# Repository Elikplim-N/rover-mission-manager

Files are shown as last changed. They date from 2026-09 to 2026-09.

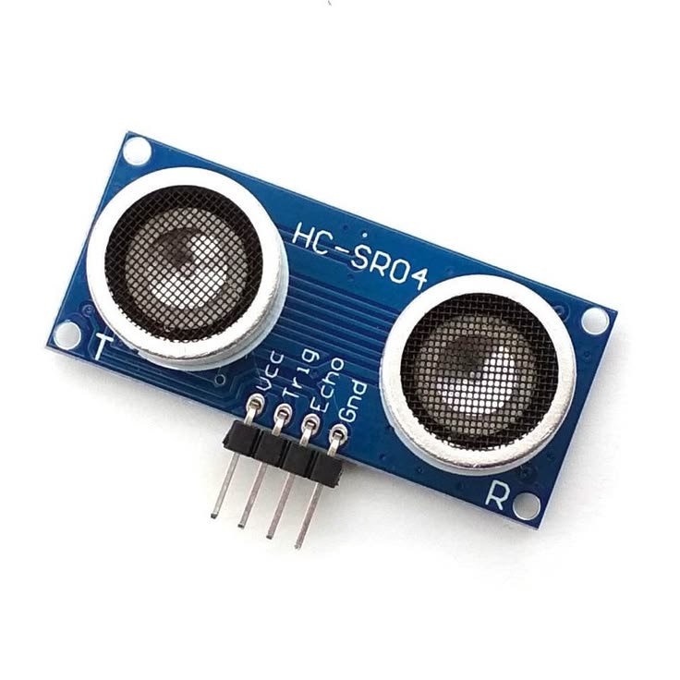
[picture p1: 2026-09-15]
docs/thesis/photos/hc_sr04_ultrasonic.jpg

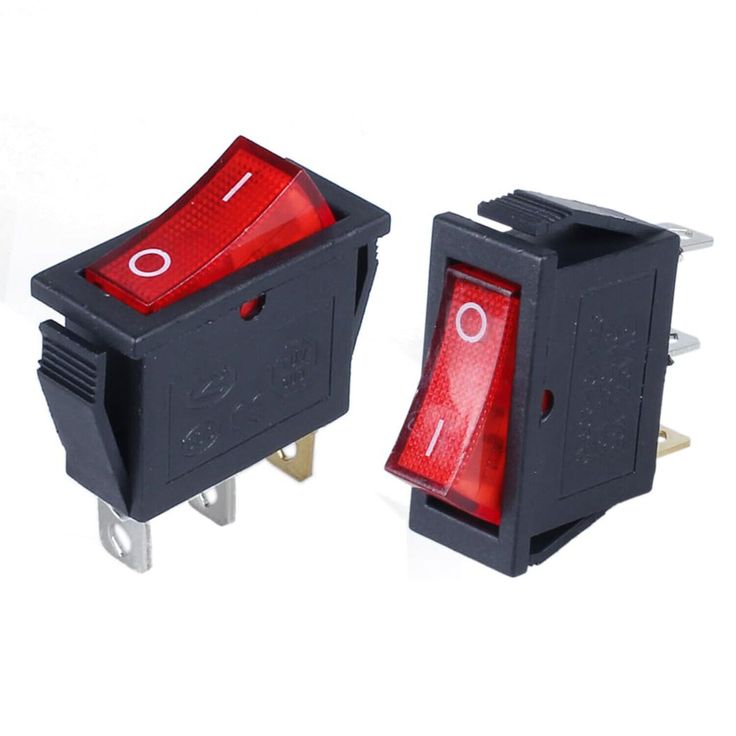
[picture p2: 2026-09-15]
docs/thesis/photos/power_rocker_switch.jpg

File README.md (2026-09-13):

# Autonomous Maize Rover: Mission Manager & Cloud IoT Ecosystem








An integrated precision agriculture cyber-physical system for autonomous maize planting, micro-irrigation, multi-sensor terrain telemetry, real-time cloud ingestion, remote E-Stop safety, and 3D digital-twin visualization.

---

## Architecture Topology

```
Sensors → Arduino Uno R4 WiFi → Wi-Fi HTTP POST → Dokploy (Node/Express + PostgreSQL 18.6) → Web Workstation
```

```mermaid
flowchart LR
    subgraph Rover["Edge: Arduino Uno R4 WiFi"]
        Sensors["BME280, MPU6050, Compass, GPS, Moisture, Ultrasonic"]
        Actuators["Motors, Seed Servo, Arm Servo, Pump Relay, Buzzer, NeoPixels"]
        MCU["Renesas RA4M1 + ESP32-S3"]
        Sensors --> MCU --> Actuators
    end

    subgraph Dokploy["Cloud: Dokploy PaaS (178.105.184.157:6000)"]
        API["rover-api (Port 3001)"]
        DB[("PostgreSQL 18.6\n(rover-hub)")]
        API --> DB
    end

    subgraph Workstation["Workstation: Rover Mission Manager"]
        ThreeD["Three.js 3D Digital Twin"]
        Analytics["Plotly.js Agronomic Analytics"]
        Teleop["Manual Control & E-Stop Room"]
        Dexie[("IndexedDB Local Cache")]
    end

    MCU -->|HTTP POST /api/telemetry| API
    MCU <-->|Direct Subnet Port 8080| Teleop
    API <-->|REST Sync & Command Relay| Workstation
    Workstation --> Dexie
```

---

## Key Features

1. **Pure Cloud-First IoT Pipeline (No SD Card)**:
   - Physical SD card breakouts are eliminated by design, avoiding SPI pin collisions with seed servos, buzzers, arm servos, and NeoPixel status lights.
   - Dedicates Pin `D4` strictly to **Left Motor Enable (`MOTOR_LEFT_EN`)**.
   - Completely removes mechanical socket vibration failures over furrow soil.
2. **Preemptive 3-State Machine & Remote E-Stop**:
   - `AUTO_MISSION`: Autonomous boustrophedon furrow traversal and periodic planting cycle.
   - `MANUAL_OVERRIDE`: Allows operator to drive the rover (WASD / arrow keys) and test individual actuators for defense demo.
   - `EMERGENCY_STOP`: Immediate remote safety kill (0% PWM, forced pump cut, warning buzzer horn, flashing red LEDs).
   - Embedded `WiFiServer` on **Port 8080** for direct `<20ms` latency control on the field Wi-Fi / mobile hotspot.
3. **Relative Micro-Topography Tare Engine**:
   - Automatically averages 12 barometric altitude samples during boot with the Bosch BME280.
   - Computes relative elevation $\Delta \text{Elev} = \text{Alt}_{\text{current}} - \text{Alt}_{\text{baseline}}$ for real-time 3D terrain reconstruction.
4. **Production Dokploy Ingestion Stack**:
   - Containerized Express REST service on port `3001`.
   - Connected live to **PostgreSQL 18.6** (`rover-hub` on `178.105.184.157:6000`).
5. **Interactive 3D Digital Twin**:
   - Three.js WebGL surface reconstruction with dynamic elevation heatmaps and boustrophedon furrow playback.
   - Smooth spherical linear interpolation (`slerp`) matching MPU-6050 pitch and roll.

---

## Repository Structure

```
├── docs/
│   └── ARCHITECTURE_KNOWLEDGE_BASE.md   # Complete system architecture specification
├── firmware/
│   ├── MaizeRover_Phase2_Master/        # Arduino Uno R4 WiFi firmware (.ino)
│   │   └── MaizeRover_Phase2_Master.ino
│   └── README.md                        # Pinout manual & hardware guide
├── server/                              # Dokploy Cloud Ingestion API
│   ├── Dockerfile                       # Production Node 20 container
│   ├── docker-compose.yml               # 1-click Dokploy stack definition
│   ├── db.js                            # PostgreSQL auto-migration & client
│   ├── index.js                         # REST endpoints (/api/telemetry, /api/command, /api/missions)
│   └── package.json
└── src/                                 # Web Application Workstation
    ├── components/
    │   ├── Layout.tsx                   # Navbar with global quick E-Stop trigger
    │   └── Terrain3D.tsx                # Three.js 3D terrain & rover kinematic visualizer
    ├── pages/
    │   ├── Dashboard.tsx                # Fleet operations & quick cloud sync
    │   ├── Teleop.tsx                   # Manual control pad, E-Stop, and actuator test bench
    │   ├── Library.tsx                  # Mission Hub & Dokploy synchronization
    │   ├── MissionView.tsx              # Detailed 3D playback & telemetry inspector
    │   ├── Analytics.tsx                # Multi-series Plotly agronomic charts
    │   ├── Fields.tsx                   # Agricultural plot boundary manager
    │   └── Planner.tsx                  # Furrow path planning & simulation
    └── lib/
        ├── api.ts                       # Dokploy REST client & direct LAN teleop driver
        ├── db.ts                        # Dexie.js IndexedDB schema
        └── utils.ts                     # Telemetry parsers & mathematical models
```

---

## 19-Channel Telemetry Schema

```csv
Row,Drop,SynX,SynY,Volt,TempC,Hum,Press,Elev,Moist,Watered,AbsHead,Err,Pitch,Roll,Lat,Lng,Sats,ObsDist
```

| Field | Type | Description |
| :--- | :--- | :--- |
| `Row`, `Drop` | Int | Furrow row index and planted drop index |
| `SynX`, `SynY`| Float (m) | Local orthogonal Cartesian grid coordinates |
| `Volt` | Float (V) | Rover battery voltage bus |
| `TempC`, `Hum`, `Press` | Float | Ambient canopy temperature (°C), humidity (%), and pressure (hPa) |
| `Elev` | Float (m) | Relative terrain micro-elevation above baseline |
| `Moist`, `Watered` | Int / Bool | Soil moisture reading (0–1023) and irrigation dose flag |
| `AbsHead`, `Err` | Float (deg) | Compass azimuth and furrow course tracking error |
| `Pitch`, `Roll` | Float (deg) | Fore-aft and transverse rover inclination angles |
| `Lat`, `Lng`, `Sats` | Float / Int | GNSS coordinates and satellite count |
| `ObsDist` | Float (cm) | Distance to nearest forward obstacle |

---

## Getting Started

### 1. Web Workstation (Frontend)
```bash
# Install dependencies
npm install

# Run locally in development mode
npm run dev
# Accessible at http://localhost:5173

# Build production bundle
npm run build
```

### 2. Dokploy Backend Deployment
```bash
cd server
npm install
npm start
# Runs on http://localhost:3001
```
Or deploy [`server/docker-compose.yml`](server/docker-compose.yml) directly in Dokploy.

### 3. Flashing the Rover
1. Open [`firmware/MaizeRover_Phase2_Master/MaizeRover_Phase2_Master.ino`](firmware/MaizeRover_Phase2_Master/MaizeRover_Phase2_Master.ino) in the Arduino IDE.
2. Select **Board: Arduino Uno R4 WiFi**.
3. Update `WIFI_SSID` and `WIFI_PASS` with your farm Wi-Fi or mobile hotspot credentials.
4. Upload to the rover.

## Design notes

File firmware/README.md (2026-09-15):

# Maize Rover: Phase 2 Master Firmware (Arduino Uno R4 WiFi)

## Architectural Model: Local-First, No Internet Required in the Field

This firmware hosts its own WiFi network (Access Point mode) instead of joining a farm router or phone hotspot. A phone or laptop connects directly to the rover's network and controls it over the local subnet — mission configuration, start/pause/resume, manual teleop, and telemetry are all served from the rover itself at a fixed address, with no dependency on mobile data or an internet connection reaching the field. A completed mission is logged on the connecting device and can be pushed to the cloud afterward, from the app, purely for later analysis.

There is also no SD card. Rather than relying on fragile physical MicroSD cards and SPI bus wiring, the Arduino Uno R4 WiFi's pins that would otherwise be reserved for an SD breakout are freed up for actuators and status indicators.

---

## Architectural Advantages of the No-SD-Card Design

1. **Elimination of Pin Contention**:
   - Standard SPI SD breakouts require pins D10 (CS), D11 (MOSI), D12 (MISO), and D13 (SCK).
   - In our rover, pins D10–D13 are dedicated to:
     - `D10`: Seed Dispenser Servo
     - `D11`: Active Buzzer
     - `D12`: Articulated Arm Servo
     - `D13`: WS2812B NeoPixel RGB
   - Eliminating the SD card frees pin `D4` completely for **Left Motor Enable (`MOTOR_LEFT_EN`)**, preventing pin conflicts and erratic motor behavior.
2. **Reduced Mechanical & Electrical Failure Points**:
   - SD card sockets frequently disconnect or corrupt files under high rover vibration over rough furrow soil.
   - Saves ~80mA current spikes from the 5V regulator.
3. **Local-First Mission Data**:
   - Every drop's telemetry is held on the rover in a live snapshot (`/cmd?action=status`) and logged by the connecting app straight to that device's own storage, with no server or connection required for the mission to run or be recorded.
   - A mission can be pushed to the cloud afterward, from the app, whenever it happens to have an internet connection — this is for later analysis only and is never on the rover's critical path.

---

## Telemetry Pipelines

1. **Pipeline 1 (Local Command/Status Server, Port 8080)**:
   - Serves mission lifecycle commands (`config`, `start_mission`, `pause_mission`, `resume_mission`, `status`) and manual teleop/E-Stop over the rover's own WiFi network.
   - `status` returns the latest telemetry snapshot and mission progress; a companion app polls this to log each drop on-device.
2. **Pipeline 2 (Local USB / Telemetry Radio)**:
   - Prints the standard 19-column CSV row at 115200 baud on USB Serial for local laptop debugging and radio receivers.

---

## Pinout Map

| Arduino Uno R4 Pin | Subsystem | Function |
| :--- | :--- | :--- |
| **A4 (SDA) / A5 (SCL)**| I2C Bus | BME280 (`0x76`), MPU-6050 (`0x68`), Compass (`0x1E`) |
| **A0** | Analog | Soil Moisture Probe |
| **A1** | Analog | Rover Battery Voltage Divider (B25 module, 5:1, 0-25V) |
| **A2 / A3** | GPIO / Timer | Ultrasonic HC-SR04 Trigger & Echo |
| **D3 / D5** | PWM | Left Motor RPWM / LPWM |
| **D4** | Digital Output | Left Motor Enable (`HIGH`) |
| **D6 / D9** | PWM | Right Motor RPWM / LPWM |
| **D7** | Digital Output | Water Pump Relay (Active LOW) |
| **D8** | Digital Output | Right Motor Enable (`HIGH`) |
| **D10** | PWM Servo | Seed Dropper Gate Servo |
| **D11** | Digital Output | Active Piezo Buzzer |
| **D12** | PWM Servo | Articulated Tool Arm Servo |
| **D13** | Digital Output | WS2812B NeoPixel Status LED Strip |
| **Serial1 (RX0/TX1)** | UART | TinyGPS++ GNSS Module @ 9600 Baud |

---

## Access Point Configuration

In `MaizeRover_Phase2_Master.ino`:
```cpp
const char* AP_SSID       = "MaizeRover-Field01";
const char* AP_PASSWORD   = "PlantMaize1";
```

Change the password before field deployment (WPA2 requires 8-63 characters). The rover always comes up at the same address, `192.168.4.1` — the WiFiS3 library's default for Access Point mode — so a phone or laptop just needs to join the `AP_SSID` network and open the app; there is no IP to look up.

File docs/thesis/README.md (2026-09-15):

# Thesis Document

`DESIGN_AND_GHANA_Final.docx` is the project report, with the following figures added in this pass (source PNGs in `figures/`):

- Figure 3.1: system block diagram, generated from the verified module architecture.
- Figure 3.3: circuit wiring diagram, generated from the pin table and cross-checked against `firmware/MaizeRover_Phase2_Master/MaizeRover_Phase2_Master.ino`.
- Figures 3.4-3.7: real screenshots of the companion web app (Mission Planner, manual override/E-Stop, 3D digital twin, Plotly elevation surface), captured from a locally running build using a sample mission from the app's own demo generator. These are captioned as interface illustrations, not field measurements.

Three placeholders were left untouched because they call for things nobody can fabricate honestly:

- Figure 3.2: a photo or CAD render of the assembled chassis. Needs an actual photo of the physical build.
- Figure 4.1: the simulated path-tracking plot. Needs real output from a completed Gazebo trial.
- Figure 4.2: a photo of the field trial plot/rover. Needs an actual photo from a real trial.

Table 4.1 and 4.2 are also still TBD, same reason: no trial data exists yet.

When those are ready, drop the photo(s) in and swap them into the matching `[Placeholder: ...]` spot in the docx, or ask Claude to do it again.

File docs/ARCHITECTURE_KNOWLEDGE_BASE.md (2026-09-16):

# Autonomous Maize Rover System: Architecture Knowledge Base

**System Name**: Autonomous Precision Agriculture Maize Rover Ecosystem  
**Target Platform**: Arduino Uno R4 WiFi (MCU, hosting its own local Access Point), Companion Mobile/Web App (Local-First Mission Control, Offline Storage, 3D Digital Twin), Optional Cloud Backend (Vercel Serverless + Dokploy-hosted PostgreSQL, for post-mission analysis only)  
**Document Classification**: Architectural Reference & Technical Knowledge Base

---

## 1. Executive System Overview & Core Architecture Axiom

> **Core Architectural Pipeline**:  
> **`Sensors → Arduino Uno R4 WiFi (hosts its own Access Point) → Local HTTP (Port 8080) → Companion App (Dexie/IndexedDB, on-device log) → [optional, when a connection exists] Cloud Push → PostgreSQL → Web Workstation (Analytics/3D Digital Twin)`**
>
> **Architectural Simplification**: Physical MicroSD card breakouts and manual CSV sneakernet file transfers are **eliminated**, and so is any dependency on field internet access. The rover hosts its own WiFi network at a fixed address; a phone or laptop joins it, configures and runs the mission, and logs every drop straight to that device's own storage. Nothing about running or recording a mission requires a server, a router, or a mobile data connection. Pushing a completed mission to the cloud is a separate, optional step the operator takes afterward, purely so the web workstation can render 3D terrain and analytics for missions they choose to share.

The system consists of three primary architectural tiers:
1. **Edge Tier (Rover Cyber-Physical Unit)**: Renesas RA4M1 32-bit MCU + ESP32-S3 Wi-Fi (Arduino Uno R4 WiFi) capturing multi-spectral environmental, inertial, and geospatial telemetry, triggering PWM/relay actuators, and hosting the local Access Point (`192.168.4.1`) that the rest of the system talks to.
2. **Application Tier (Companion App, Local-First)**: An installable Progressive Web App built with React 19, TypeScript, Three.js, and Plotly. It connects to the rover over its Access Point, drives the mission configuration/start/pause/resume lifecycle, and is the sole place a mission's telemetry is logged in the field, via Dexie.js (IndexedDB). It works fully offline and is the same application used later for analysis.
3. **Cloud Tier (Optional, Post-Mission Analysis Only)**: A PostgreSQL 18.6 database hosted on Dokploy, reached either through Vercel serverless functions (the deployed production frontend) or a standalone Node.js/Express service (for local/self-hosted use). The rover itself never talks to this tier; the app pushes a completed mission to it only when the operator chooses to and a connection happens to be available.

```mermaid
flowchart TB
    subgraph EdgeTier["Edge Tier: Maize Rover (Arduino Uno R4 WiFi)"]
        Sensors["Sensors: Dual MPU-6050 (0x68 Steering Gyro, 0x69 Roughness Accel), GPS, Moisture"]
        Actuators["Actuators: Drive Motors, Seed Servo, Water Pump"]
        MCU["Renesas RA4M1 MCU + ESP32-S3 Wi-Fi Coprocessor\n(Hosts Access Point: 192.168.4.1)"]
        Sensors --> MCU
        MCU --> Actuators
    end

    subgraph LocalPipes["Local-First Pipelines (No Internet Required)"]
        SerialOut["Pipeline 2: USB / Radio Serial Stream (115200 Baud, debugging)"]
        CmdServer["Pipeline 1: Port 8080 Command/Status Server\n(config, start/pause/resume_mission, status, teleop, e-stop)"]
        MCU --> SerialOut
        MCU --> CmdServer
    end

    subgraph AppTier["Application Tier: Companion App (Installable PWA)"]
        DexieDB[("Browser IndexedDB\n(Dexie.js — on-device mission log)")]
        ThreeD["Three.js 3D Digital Twin & Terrain Engine"]
        PlotlyAnalytics["Plotly.js Agronomic Analytics"]
        MissionCtl["Mission Control (connect, configure, run, poll status)"]

        CmdServer <-->|Joins the rover's WiFi AP| MissionCtl
        MissionCtl --> DexieDB
        SerialOut -.->|Serial CSV Import| DexieDB
        DexieDB --> ThreeD
        DexieDB --> PlotlyAnalytics
    end

    subgraph CloudTier["Cloud Tier (Optional): PostgreSQL on Dokploy"]
        VercelAPI["Vercel Serverless Functions (api/*.js)\nor self-hosted rover-api (server/, Node.js/Express)"]
        PostgresDB[("PostgreSQL 18.6 Database\n(rover-hub: missions & telemetry_points)")]
        VercelAPI --> PostgresDB
    end

    DexieDB -.->|"Operator chooses to push/pull\n(only when online)"| VercelAPI
```

---

## 2. Edge Tier Architecture (Firmware & Embedded Hardware)

### 2.1 Microcontroller Constraints & Local-First Architecture

| Hardware Parameter | Specification | Architectural Consequence | Architectural Decision (Local-First) |
| :--- | :--- | :--- | :--- |
| **Microcontroller** | Renesas RA4M1 (Arm Cortex-M4 @ 48 MHz) | 32-bit execution, native USB, FPU | Real-time trigonometric coordinate dead-reckoning and orientation filters. |
| **SRAM** | 32 KB | Volatile; erased upon battery disconnect | SRAM holds active loop state, mission parameters, and the latest telemetry snapshot only. |
| **Data Flash (EEPROM)** | 8 KB | Limited to ~75 telemetry lines | Bypassed. The rover never accumulates a mission log itself; the companion app logs each drop as it happens. |
| **Physical SD Card** | *Omitted by Design* | Pins D10–D13 conflict with servos/buzzer/LEDs; pin D4 needed for motor enable | **Eliminated**. Avoids SPI bus pin contention, eliminates mechanical vibration failure on rough soil, and saves ~80mA current spikes. |
| **Primary Telemetry** | ESP32-S3 Coprocessor (Uno R4 WiFi) | 2.4 GHz 802.11 b/g/n Wi-Fi, in Access Point mode | **Local Status Snapshot**: the rover hosts its own network at `192.168.4.1` and exposes the latest drop's telemetry via `GET /cmd?action=status`; the connecting app polls this and logs it on-device. The rover has no path to the internet by design and never pushes telemetry itself. |
| **Secondary Telemetry** | USB CDC Serial (115200 Baud) | Real-time CSV line printing | Live local workstation/field laptop telemetry mirror for bench debugging. |

### 2.2 Pinout & Peripheral Assignment

```
Arduino Uno R4 Pinout
├── I2C Bus (Pins A4/SDA, A5/SCL, shared by both boards below)
│   ├── MPU-6050 #1 "Steering" (0x68, AD0=GND): Gyro Z-rate for closed-loop
│   │   local relative-yaw-hold PID + turn tracking; accelerometer XY/Z also
│   │   read for Pitch & Roll inclination angles
│   └── MPU-6050 #2 "Roughness" (0x69, AD0=VCC): Z-axis accelerometer only,
│       peak deviation from 1g sampled at 200Hz as a terrain-shock metric
│
│   NOTE: The BME280 (temp/humidity/pressure/altitude) and the HMC5883L /
│   QMC5883L magnetometer from earlier hardware revisions have been removed.
│   The magnetometer proved too electromagnetically noisy this close to the
│   brushed-DC drive motors to hold a reliable heading; the second MPU-6050
│   above replaces it with gyro-integrated relative yaw instead.
├── Analog Inputs
│   ├── A0: Soil Moisture Probe (0 - 1023 ADC raw resistance/capacitance)
│   └── A1: Battery Voltage Divider (B25 module, 5:1 divider, 0-25V range)
├── Actuators & Motor Control
│   ├── D3 (PWM): Left Motor Forward (RPWM)
│   ├── D4 (GPIO): Left Motor Enable / Remappable SPI CS
│   ├── D5 (PWM): Left Motor Reverse (LPWM)
│   ├── D6 (PWM): Right Motor Forward (RPWM)
│   ├── D7 (GPIO): Water Pump Relay (Active LOW actuation)
│   ├── D8 (GPIO): Right Motor Enable
│   ├── D9 (PWM): Right Motor Reverse (LPWM)
│   ├── D10 (PWM): Seed Dispenser Hopper Servo (0° closed, 60° open gate)
│   ├── D11 (PWM): Piezo Buzzer (acoustic system alert)
│   └── D13 (GPIO): WS2812B NeoPixel RGB Status Array (Green = Run, Red = E-Stop, Amber = Init)
└── Serial Interfaces
    ├── Serial (USB CDC): Primary telemetry output stream @ 115200 Baud
    └── Serial1 (D0 RX, D1 TX): GNSS / GPS Receiver @ 9600 Baud (TinyGPS++)
```

NOTE: The HC-SR04 ultrasonic obstacle sensor and the articulated soil-probe
arm servo (formerly D12) have also been physically removed from this
hardware revision. Unlike the BME280/compass fields above, their telemetry
(`obsDist`) and command (`test_arm`) were deleted outright rather than
zeroed, since a fake "0cm to obstacle" reading would be actively misleading
rather than simply unavailable. There is currently no obstacle-avoidance
sensor on the rover.

### 2.3 Sensor Processing & Mathematical Transformations

1. **Terrain Roughness (`Roughness`)**:
   - MPU-6050 #2 (0x69) is read at 200Hz throughout every straight-line drive segment. Each sample computes deviation of the Z-axis accelerometer from stationary 1g:
     $$\text{Shock} = \left| a_{z} - 1.0g \right|$$
   - The telemetry value reported is the **running peak**, not an average, so one significant bump over rough ground is not smoothed away by an otherwise calm segment:
     $$\text{Roughness} = \max(\text{Shock}_1, \text{Shock}_2, \dots, \text{Shock}_n) \text{ over the segment}$$
   - This replaces the earlier BME280-based relative-elevation figure. This hardware revision has no barometric sensor, so `Elev`, `TempC`, `Hum`, and `Press` are always reported as `0.0` in every log — the columns are kept, not deleted, purely for CSV/JSON schema compatibility with existing tooling.
2. **Synthetic Dead-Reckoning Grid (`SynX`, `SynY`)**:
   - In field environments where GNSS precision suffers from multipath error or tree canopy cover, the rover tracks row and drop indices using boustrophedon (serpentine) navigation:
     - For odd rows ($Row \pmod 2 \neq 0$): $\text{SynX} = (Drop - 1) \times S_{\text{drop}}$
     - For even rows ($Row \pmod 2 = 0$): $\text{SynX} = (N_{\text{drops}} - Drop) \times S_{\text{drop}}$
     - In both rows: $\text{SynY} = (Row - 1) \times S_{\text{row}}$
3. **Local Relative-Yaw Steering Error (`Err`) & Digital-Compass Heading (`AbsHead`)**:
   - There is no absolute heading reference on this hardware revision (no magnetometer). Every call to the straight-line PID resets a **local yaw integral to 0°** and holds it there by integrating MPU-6050 #1's (0x68) gyro Z-rate at 50Hz:
     $$\text{localYaw}(t) = \int_{t_0}^{t} \dot{\theta}_{z}\,dt, \quad \text{reset to } 0 \text{ at the start of each segment}$$
   - `Err` is simply the live `localYaw` value at the most recent control tick — the PID's own tracking error, not a deviation from a compass bearing.
   - `AbsHead` is a **separate**, best-effort estimate: `globalYaw`, the same gyro-rate integration accumulated continuously since boot and never reset. It is exposed for logging and 3D-twin orientation only, is expected to drift over a long mission since nothing ever corrects it, and must not be treated as a true compass azimuth.

### 2.4 Operational State Machine & Teleoperation Architecture

To support a simple mission lifecycle (configure, start, pause mid-field, resume, complete) alongside testing and field safety, the rover firmware implements a five-state machine:

```mermaid
stateDiagram-v2
    [*] --> IDLE : Power On / Reset (Access Point up)
    IDLE --> AUTO : start_mission (after optional config)
    AUTO --> PAUSED : pause_mission
    PAUSED --> AUTO : resume_mission
    AUTO --> IDLE : Mission Complete (all rows planted)

    IDLE --> MANUAL : Directional Nudge / Actuator Test
    AUTO --> MANUAL : Directional Nudge / Actuator Test
    PAUSED --> MANUAL : Directional Nudge / Actuator Test
    MANUAL --> AUTO : Operator "Resume Auto" Command

    IDLE --> ESTOP : Remote E-Stop / Voltage Failsafe
    AUTO --> ESTOP : Remote E-Stop / Voltage Failsafe
    PAUSED --> ESTOP : Remote E-Stop / Voltage Failsafe
    MANUAL --> ESTOP : Remote E-Stop / Voltage Failsafe
    ESTOP --> MANUAL : Operator "Clear E-Stop"
```

#### Key Capabilities:
1. **Local Mission Lifecycle**:
   - `config`: applies grid geometry, drive speed, and moisture threshold before or between runs; all parameters optional.
   - `start_mission`: resets the row/drop counters and begins autonomous traversal from `IDLE`.
   - `pause_mission` / `resume_mission`: holds and restores the exact row/drop position, so a mission can be safely interrupted mid-field (e.g. to clear an obstacle by hand) and continued later.
   - `status`: read-only snapshot of mode, mission progress, and the latest drop's full telemetry, polled by the companion app to log each drop on-device.
2. **Testing & Defense Demo Mode**:
   - Allows operator to drive the rover to a furrow starting point without triggering an autonomous planting cycle.
   - Independent actuator test bench: single seed kernel drop (Hopper Servo D10), single water micro-dose 400ms pulse (Relay D7).
3. **Safety & Remote E-Stop**:
   - Preempts all states immediately. Forces motor PWM to 0, cuts pump power, activates continuous horn tone and flashing red NeoPixels.
   - Global E-Stop trigger accessible in header navigation bar across the entire companion app.
4. **Local-First Command Channel**:
   - **Rover's own Access Point (Port 8080)**: Direct HTTP GET commands (`http://192.168.4.1:8080/cmd?action=...`) with $<20\text{ ms}$ latency once the phone/laptop has joined the rover's WiFi network. This is the **only** channel the app uses. An earlier revision fell back to a cloud relay (`POST /api/command`) when the direct link failed; that fallback was removed because it could silently report a false "success" that never reached the physical rover. If `directRoverIp` isn't configured, or the direct request fails, the app now surfaces the error instead of retrying through the cloud.
5. **Deadman Safety Timeout**:
   - In `MANUAL`, motors automatically stop if no directional command is received within **600ms**, preventing rover runaway on lost WiFi packets.

---

## 3. Telemetry Protocol Specification

Every drop is recorded using the same exact 19-column schema everywhere it appears: the rover's local `/cmd?action=status` snapshot, its USB CSV mirror, and the companion app's on-device Dexie log:

```csv
Row,Drop,SynX,SynY,Volt,TempC,Hum,Press,Elev,Moist,Watered,AbsHead,Err,Pitch,Roll,Lat,Lng,Sats,Roughness
```

`Roughness` is new in this hardware revision; the cloud `telemetry_points` schema (Section 4.2) does not yet have a matching column, so it is currently dropped, not persisted, if a mission is pushed to the cloud for analysis.

### 3.1 Field Dictionary

| Column | JSON Key | Type | Unit | Range | Description |
| :--- | :--- | :--- | :--- | :--- | :--- |
| **Row** | `row` | Integer | - | $1 \dots \infty$ | Furrow index across the agricultural plot |
| **Drop** | `drop` | Integer | - | $1 \dots N$ | Planted seed index within the active furrow |
| **SynX** | `synX` | Float | m | $0.00 \dots X_{\max}$ | Local orthogonal Cartesian X-coordinate |
| **SynY** | `synY` | Float | m | $0.00 \dots Y_{\max}$ | Local orthogonal Cartesian Y-coordinate |
| **Volt** | `volt` | Float | V | $0.00 \dots 14.80$ | Rover power bus battery voltage |
| **TempC** | `tempC` | Float | °C | always `0.0` | **Removed.** BME280 not present on this hardware revision; field kept for schema compatibility |
| **Hum** | `hum` | Float | % | always `0.0` | **Removed.** BME280 not present on this hardware revision; field kept for schema compatibility |
| **Press** | `press` | Float | hPa | always `0.0` | **Removed.** BME280 not present on this hardware revision; field kept for schema compatibility |
| **Elev** | `elev` | Float | m | always `0.0` | **Removed.** BME280 not present on this hardware revision; field kept for schema compatibility |
| **Moist** | `moist` | Integer | raw | $0 \dots 1023$ | Volumetric soil moisture sensor reading |
| **Watered**| `watered`| Boolean| flag | $0 \text{ or } 1$ | Whether localized irrigation dose was dispensed |
| **AbsHead**| `absHead`| Float | deg | unbounded, drifts | `globalYaw`: gyro-integrated estimate accumulated since boot (MPU-6050 0x68). **Not** a magnetic compass azimuth — no magnetometer on this hardware revision |
| **Err** | `err` | Float | deg | typically $-30 \dots 30$| Live local relative-yaw PID error (`localYaw`) for the current drive segment, reset to 0° at the start of each segment |
| **Pitch** | `pitch` | Float | deg | $-90.0 \dots 90.0$ | Longitudinal rover inclination (fore/aft slope), from MPU-6050 #1 (0x68) accelerometer |
| **Roll** | `roll` | Float | deg | $-90.0 \dots 90.0$ | Transverse rover inclination (port/starboard slope), from MPU-6050 #1 (0x68) accelerometer |
| **Lat** | `lat` | Float | deg | $-90.0 \dots 90.0$ | WGS84 GPS Latitude |
| **Lng** | `lng` | Float | deg | $-180.0 \dots 180.0$| WGS84 GPS Longitude |
| **Sats** | `sats` | Integer | count| $0 \dots 32$ | Visible and locked GNSS satellite count |
| **Roughness**| `roughness`| Float | g | $0.0 \dots \sim 2.0$| Peak Z-axis accelerometer deviation from 1g during the segment, from MPU-6050 #2 (0x69) sampled at 200Hz |

---

## 4. Cloud Backend Architecture (Optional, Post-Mission Analysis Only)

This tier exists purely so a mission the operator has already logged locally can be pushed somewhere for 3D/analytics review later; nothing about running a mission depends on it, and the rover never talks to it directly. Two deployment shapes share the same PostgreSQL schema and a near-identical REST contract:

1. **Production deployment**: the companion app is hosted on **Vercel**, and `/api/*` is served by Vercel Serverless Functions (`api/health.js`, `api/missions.js`, `api/command.js`, `api/telemetry.js`) that connect straight to a PostgreSQL instance hosted on **Dokploy**.
2. **Self-hosted / local dev deployment**: a standalone Node.js/Express service (`server/index.js`) exposing the same endpoints, for running the whole stack (app + API + DB) under Dokploy or on a laptop without Vercel.

### 4.1 Production Database Infrastructure
- **DBMS**: PostgreSQL 18.6 (Debian 18.6), hosted on Dokploy
- **Database**: `rover-hub`
- **Connection**: supplied via the `DATABASE_URL` environment variable in both deployment shapes; never hardcoded in documentation. Rotate the credential in the Dokploy dashboard and both deployments' environment variables if it has ever been shared outside the team.
- **Current Status**: Live and active; schema (`missions`, `telemetry_points`) migrated. The Vercel deployment additionally uses `rover_commands` and `rover_status` tables to persist the teleop command relay across serverless invocations (the self-hosted Express service keeps that same state in memory instead, since it runs as a single long-lived process).

```mermaid
flowchart LR
    subgraph Vercel["Vercel (Production Frontend + Serverless API)"]
        VercelAPI["api/*.js Serverless Functions"]
    end
    subgraph SelfHosted["Self-Hosted Alternative (Dokploy / local dev)"]
        ExpressAPI["server/index.js (Node.js/Express)"]
    end
    subgraph DokployDB["Dokploy-Hosted Database"]
        PG[("PostgreSQL 18.6\n(rover-hub)")]
    end

    VercelAPI -->|DATABASE_URL| PG
    ExpressAPI -->|DATABASE_URL| PG
    App(("Companion App\n(pushes a completed mission\nwhen the operator chooses to)")) -.->|POST /api/missions| VercelAPI
    App -.->|POST /api/missions| ExpressAPI
```

### 4.2 Relational Database Schema (PostgreSQL)

```sql
-- Missions Table: High-level mission run metadata
CREATE TABLE missions (
    id VARCHAR(64) PRIMARY KEY,
    name VARCHAR(255) NOT NULL,
    config_id VARCHAR(64),
    field_id VARCHAR(64),
    start_time TIMESTAMPTZ NOT NULL,
    end_time TIMESTAMPTZ,
    tags JSONB DEFAULT '[]'::jsonb,
    created_at TIMESTAMPTZ DEFAULT NOW(),
    updated_at TIMESTAMPTZ DEFAULT NOW()
);

-- Telemetry Points Table: Time-series drop observations
CREATE TABLE telemetry_points (
    id BIGSERIAL PRIMARY KEY,
    mission_id VARCHAR(64) REFERENCES missions(id) ON DELETE CASCADE,
    row_num INT NOT NULL,
    drop_num INT NOT NULL,
    syn_x FLOAT NOT NULL,
    syn_y FLOAT NOT NULL,
    volt FLOAT,
    temp_c FLOAT,
    hum FLOAT,
    press FLOAT,
    elev FLOAT,
    moist INT,
    watered BOOLEAN DEFAULT false,
    abs_head FLOAT,
    err FLOAT,
    pitch FLOAT,
    roll FLOAT,
    lat FLOAT,
    lng FLOAT,
    sats INT DEFAULT 0,
    obs_dist FLOAT, -- Legacy column: the ultrasonic sensor that populated this has been
                    -- physically removed from the rover; existing rows keep their real
                    -- historical readings, but every new row inserts NULL here (both API
                    -- deployments already fall back to NULL when this field is absent).
    recorded_at TIMESTAMPTZ DEFAULT NOW()
);

CREATE INDEX idx_telemetry_mission ON telemetry_points(mission_id);
CREATE INDEX idx_telemetry_row_drop ON telemetry_points(mission_id, row_num, drop_num);

-- Additional tables used only by the Vercel serverless deployment, to persist
-- the teleop command relay state across invocations (the self-hosted Express
-- service keeps this in an in-memory variable instead, since it runs as one
-- long-lived process rather than per-request functions).
CREATE TABLE rover_commands (
    id BIGSERIAL PRIMARY KEY,
    action VARCHAR(32) NOT NULL,
    params JSONB DEFAULT '{}'::jsonb,
    created_at TIMESTAMPTZ DEFAULT NOW()
);

CREATE TABLE rover_status (
    id INT PRIMARY KEY,
    mode VARCHAR(16) DEFAULT 'AUTO',
    last_seen TIMESTAMPTZ,
    volt FLOAT,
    lat FLOAT,
    lng FLOAT,
    updated_at TIMESTAMPTZ DEFAULT NOW()
);
```

### 4.3 REST API Endpoints

All of these are optional from the rover's perspective — they exist for the companion app to sync a mission for later analysis, and for bench-testing teleop off the rover's own network. The rover itself only ever speaks to its local `/cmd` server (Section 2.4).

- `GET /api/health`: Health probe and service/database status.
- `GET /api/missions`: Returns list of all missions with their telemetry points, for the companion app's cloud sync/import.
- `GET /api/missions/:id`: Returns a single mission with all ordered telemetry points (self-hosted deployment only; the Vercel deployment returns full telemetry inline from `GET /api/missions`).
- `POST /api/missions`: Bulk ingest of a completed mission run, pushed by the app once the operator opts to sync it.
- `POST /api/command` / `GET /api/command`: Optional cloud relay for teleop commands, used only as a fallback when the app cannot reach the rover's own Access Point directly.
- `POST /api/telemetry`: Legacy per-drop streaming endpoint, retained for the self-hosted deployment's live-dashboard demo mode; not used by the rover firmware, which no longer has direct internet access.

---

## 5. Frontend Workstation Architecture (Web Application)

### 5.1 Tech Stack & Design Principles
- **Core Framework**: React 19, TypeScript, Vite, packaged as an installable Progressive Web App (manifest + precaching service worker) so it launches from a phone's home screen and its app shell loads with zero connectivity.
- **Client Storage**: Dexie.js (IndexedDB wrapper). This is not just an offline cache — it is the primary, authoritative log of every mission run in the field; cloud sync is a secondary copy made afterward, by choice.
- **Mission Control**: connects to the rover's Access Point, drives the `config`/`start_mission`/`pause_mission`/`resume_mission` lifecycle, and polls `status` to build up the local mission log drop by drop as it runs.
- **3D Visualization**: Three.js WebGL rendering with custom procedural terrain geometry, elevation heatmap vertex coloring, and animated rover mesh traversal.
- **Data Analytics**: Plotly.js for multi-series correlation (Soil Moisture vs Irrigation, Battery Voltage curves, Heading Error distributions).
- **UI Design System**: Tailwind CSS v4, Lucide SVG icons, zero-emoji professional engineering workstation standard, responsive drawer navigation.

### 5.2 3D Terrain Reconstruction Engine (`Terrain3D.tsx`)
1. **Grid Generation**: Calculates bounding box from $(\text{SynX}, \text{SynY})$ or translated GPS coordinates.
2. **Elevation Warping**: Maps barometric relative elevation (`Elev`) to surface vertex heights using inverse-distance weighting (IDW) interpolation. **Currently flat**: `Elev` is always `0.0` on this hardware revision since the BME280 was removed; this engine has no elevation source until one is reinstated or a proxy (e.g. `Roughness`) is wired in instead.
3. **Agronomic Heatmap**: Vertex shader interpolates between deep green (low elevation/furrow bottoms) to sandy yellow and reddish-brown (high terrain ridges).
4. **Kinematic Playback**: Smooth spherical linear interpolation (`slerp`) of rover orientation, pitching and rolling according to real MPU-6050 telemetry data points.

---

## 6. End-to-End Sequence Diagram

```mermaid
sequenceDiagram
    autonumber
    participant R as Arduino Rover (Uno R4 WiFi, hosts 192.168.4.1)
    participant A as Companion App (phone/laptop, offline)
    participant S as Cloud Backend (Vercel/Express + PostgreSQL)

    Note over R: Boot: dual-MPU-6050 wake + gyro Z-offset calibration, host Access Point
    A->>R: Join rover's WiFi network
    A->>R: GET /cmd?action=config&... (optional grid/speed/moisture params)
    A->>R: GET /cmd?action=start_mission
    R-->>A: {"ok":true,"mode":"AUTO"}

    loop Every Planting Drop
        R->>R: Read dual MPU-6050 (0x68 steering gyro + 0x69 roughness accel), GPS, Moisture
        R->>R: Calculate synX, synY, peak roughness for the segment
        R->>R: Actuate seed hopper servo & water pump
        R->>R: Output CSV line to USB CDC Serial (115200 Baud)
        R->>R: Update latest telemetry snapshot (telemetrySeq++)
        A->>R: GET /cmd?action=status (poll ~every 1.5s)
        R-->>A: Latest mode, mission progress, telemetry snapshot
        A->>A: New seq? Append drop to local MissionRun (Dexie)
    end

    opt Operator pauses mid-field
        A->>R: GET /cmd?action=pause_mission
        Note over R: Holds row/drop position, motors off
        A->>R: GET /cmd?action=resume_mission
        Note over R: Continues from exactly where it left off
    end

    R->>R: All rows planted: missionComplete = true, mode -> IDLE
    A->>A: Mark local MissionRun endTime, ready for review

    opt Operator chooses to sync for analysis (only when online)
        A->>S: POST /api/missions (completed mission + telemetry)
        S->>S: Insert into PostgreSQL missions & telemetry_points
        A->>A: Render 3D Terrain Digital Twin, Path Playback & Analytics
    end
```

---

## 7. Claude Prompting Cheat-Sheet (Architecture Documentation Generator)

To generate complete architectural documentation, specifications, or academic reports with Claude, use the following system prompt and input context:

### Prompt Template for Claude:
```text
You are an expert Autonomous Robotics & Precision Agriculture Systems Architect.
Using the provided "Autonomous Maize Rover System: Architecture Knowledge Base", complete the detailed system architecture documentation.

Follow these strict guidelines:
1. Preserve the 19-column telemetry specification without omitting any column.
2. Explain the hardware limitations of the Arduino Uno R4 (8KB Data Flash vs 32KB volatile SRAM) and justify why the rover hosts its own WiFi Access Point and logs nothing itself, leaving mission storage to the companion app.
3. Detail the dual-MPU-6050 architecture: gyro-integrated local relative-yaw-hold PID steering (0x68, no magnetometer) and peak Z-axis shock terrain-roughness sensing (0x69, 200Hz).
4. Provide the exact PostgreSQL relational schema for the optional cloud analysis backend, and be explicit that it is not on the rover's critical path.
5. Emphasize the local-first IndexedDB (Dexie) design pattern: it is the authoritative mission log, not a cache, and the same app is used for logging in the field and analysis afterward.
6. Maintain an academic, professional engineering tone with clean ASCII or Mermaid diagrams and no emojis.
```

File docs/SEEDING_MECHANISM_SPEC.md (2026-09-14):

# Autonomous Maize Rover: Rotary Drum Seeding Mechanism Design

**Mechanism Type**: Direct-Coupled Oscillating Rotary Drum (Cylindrical Rotor Pod)  
**Actuator**: TowerPro MG996R / DS3218 Metal-Gear High-Torque Servo (Pin D10)  
**Mounting Interface**: 4× M4 Socket Head Bolts to Rover Chassis Plate  
**Seed Target**: Zea mays (Maize / Corn: ~9–12 mm kernel length, ~6–8 mm width)

---

## 1. Engineering 3D CAD Visualization

Modular Seeder Pod

---

## 2. Working Principle: Oscillating Rotor with Flexible Anti-Pinch Wiper

The **Rotary Drum Metering Pod** replaces linear sliders with a cylindrical barrel rotating inside a precision-bored stator sleeve. The servo is directly coupled coaxially to the rotor shaft, eliminating push-rods, linkages, and exposed slide rails that could bind from field soil and dust.

```mermaid
sequenceDiagram
    autonumber
    participant H as Conical Hopper (Top)
    participant W as Flexible Wiper Brush
    participant R as Cylindrical Drum Rotor
    participant C as Discharge Chute (Bottom)

    Note over R: Position 0° (Fill / Standby)
    H->>R: One maize kernel falls by gravity into the top calibrated pocket
    Note over R: Servo rotates 0° -> 90° CW (Discharge Stroke)
    R->>W: Pocket sweeps past flexible wiper brush; excess kernels swept back without crushing
    Note over R: Position 90° (Discharge Alignment)
    R->>C: Pocket inverts directly over drop tube; kernel free-falls into furrow
    Note over R: Servo rotates 90° -> 0° CCW (Return Stroke)
    R->>H: Pocket returns to top vertical alignment to reload next seed
```

---

## 3. Key Advantages of the Rotor Design

| Engineering Criteria | Rotary Drum Metering Pod | Linear Slider / Drawer |
| :--- | :--- | :--- |
| **Mechanical Simplicity** | **Direct Drive**: Rotor mounts directly on the 25T servo output shaft or via flexible coupler. Zero linkages. | Requires a crank arm, pushrod, ball-joints, and guide tracks. |
| **Dust & Soil Sealing** | **Enclosed Stator Barrel**: Sealed radial fit prevents dirt, chaff, and grit from entering internal surfaces. | Exposed slide rails can collect grit and increase friction over time. |
| **Cycle Speed** | **Fast (120ms)**: Smooth rotational sweep with zero linear reversal inertia. | Slower due to slider friction and reciprocal stopping points. |
| **Seed Protection** | **Tangential Shearing Path**: Kernel rolls smoothly against the flexible bristle wiper into the pocket. | Linear edges can wedge kernels against flat walls. |

---

## 4. Mechanical Mounting to Rover Chassis

```
                      [ Conical Seed Hopper ]
                                 │
                 ┌───────────────▼───────────────┐
                 │    Stator Housing Sleeve      │════[ MG996R Servo ]
                 │   (Contains Rotary Drum)      │ (Direct Coaxial Shaft)
                 └───────────────┬───────────────┘
                                 │
                   [ Heavy-Duty Mounting Flange ]
                                 │ (4x M4 Hex Socket Bolts)
        ═════════════════════════╪═══════════════════════════════════ (Rover Chassis Plate)
                                 │
                      [ Angled Drop Tube Chute ]
                                 │
                                 ▼ (Directly behind Furrow Opener Blade)
```

1. **Chassis Bolt Pattern**:
   - The pod base features **4× M4 clearance slots** arranged in a rectangular pattern ($60\text{ mm} \times 45\text{ mm}$).
   - Fastened to the rover's aluminum chassis plate using **M4 × 16 mm Socket Head Cap Screws** with lock washers and nylon lock nuts.
   - Slotted base holes provide **$\pm12\text{ mm}$ of vertical height adjustment** to tune drop height relative to the furrow bottom.
2. **Chassis Positioning**:
   - Located on the longitudinal centerline directly trailing the furrow opener shoe and leading the furrow closing press wheel and micro-irrigation drip nozzle.
3. **Vibration Decoupling**:
   - A 2mm neoprene rubber dampening pad is sandwiched between the dispenser mounting flange and the rover body to absorb vibrations from rough agricultural terrain.
4. **Wiring Pass-Through**:
   - Servo 3-pin cable routes directly through an integrated rear grommet channel into the sealed rover body to Arduino Uno R4 Pin **D10**.

---

## 5. Anti-Jamming & Singulation Engineering

1. **Flexible Wiper Brush Lip**:
   - Located at the 45° transition between the hopper throat and the stator wall.
   - Made of dense nylon bristles (or 2mm food-grade silicone squeegee flap).
   - As the drum rotates, the wiper brushes away secondary kernels without cracking the seed coat or stalling the servo.
2. **Calibrated Teardrop Pocket Geometry**:
   - Pocket dimensions: **13 mm length × 8.5 mm width × 7 mm depth**.
   - Chamfered $45^\circ$ internal lead-in fillet ensures a flat maize seed settles naturally into the cavity by gravity.
3. **High-Torque Metal Gearhead**:
   - The **MG996R** delivers **$11\text{ kg}\cdot\text{cm}$ of stall torque**, easily overcoming any light friction from corn chaff or dry seed coatings.

---

## 6. Firmware Actuation Routine

Mapped directly to `MaizeRover_Phase2_Master.ino`:

```cpp
// Seeding Actuation on Pin D10
#define SEED_SERVO_PIN 10
Servo seedServo;

void setup() {
  seedServo.attach(SEED_SERVO_PIN);
  seedServo.write(0); // 0°: Standby fill position (pocket facing hopper throat)
}

void actuateSeedDrop() {
  // 1. Rotate drum 90° CW to discharge aperture
  seedServo.write(90);  // 90°: Pocket inverts over drop chute
  delay(180);           // 180ms gravity ejection delay
  
  // 2. Return drum to 0° CCW to reload for next furrow step
  seedServo.write(0);   // 0°: Pocket reloads under hopper
  delay(100);
}
```

---

## 7. Bill of Materials (BOM)

| Item | Component | Recommended Material | Qty |
| :---: | :--- | :--- | :---: |
| **1** | Stator Outer Housing & Mount Flange | 3D Printed PETG / ABS (0.2mm layer, 4 perimeters, 40% infill) | 1 |
| **2** | Cylindrical Metering Rotor Drum | 3D Printed PETG or CNC Machined Delrin / Brass | 1 |
| **3** | Seed Hopper (500 ml) | Clear Molded PETG / Acrylic Cone (60° steep slope) | 1 |
| **4** | Servo Motor | TowerPro MG996R or DS3218 Metal Gear Standard Servo | 1 |
| **5** | Flexible Anti-Jam Wiper | Dense Nylon Bristle Strip (12mm width) or 2mm Silicone Flap | 1 |
| **6** | Servo Shaft Coupler | 25T Aluminum Spline Horn or 5mm-to-6mm Rigid Shaft Coupler | 1 |
| **7** | Chassis Mounting Bolts | M4 × 16 mm Stainless Steel Hex Socket Screws + Lock Nuts | 4 |
| **8** | Housing Assembly Fasteners | M3 × 12 mm Button Head Screws + Brass Heat-Set Inserts | 4 |
| **9** | Furrow Drop Tube | Ø20 mm Polycarbonate / Clear Acrylic Tube (beveled tip) | 1 |

---

## 8. Downloadable 3D-Printable STL Models

All 3 components are 100% Watertight (Manifold) and ready to slice:

1. 🏛️ **[Modular Chassis Base with MG996R Motor Mount (`modular_seeder_chassis_base.stl`)](https://github.com/Elikplim-N/rover-mission-manager/blob/main/models/stl/modular_seeder_chassis_base.stl)**:
   - Dedicated 4-bolt MG996R motor mount ($49.5\text{ mm} \times 10.0\text{ mm}$ ear screw holes).
   - Heavy-duty chassis mounting flange with 4x M4 slotted holes ($64\text{ mm} \times 36\text{ mm}$ pattern).
   - Integrated lower drop chute nozzle & wire strain relief conduit.
2. 🔄 **[Modular Rotor Drum (`modular_seeder_rotor.stl`)](https://github.com/Elikplim-N/rover-mission-manager/blob/main/models/stl/modular_seeder_rotor.stl)**:
   - Precision maize seed pocket with 35° forward relief ramp.
   - Dual perimeter agitator ridges preventing hopper bridging.
   - 8mm front axle stub + rear 25T metal servo horn recess.
3. 🛡️ **[Modular Front Cover (`modular_seeder_front_cover.stl`)](https://github.com/Elikplim-N/rover-mission-manager/blob/main/models/stl/modular_seeder_front_cover.stl)**:
   - 608ZZ ball bearing seat ($22.1\text{ mm} \times 7.2\text{ mm}$).
   - Top circular hopper mounting collar (Ø38mm OD, Ø24mm throat).
   - Flexible silicone wiper blade retention slot.
4. 📦 **[Full Reference Assembly (`modular_seeder_full_assembly.stl`)](https://github.com/Elikplim-N/rover-mission-manager/blob/main/models/stl/modular_seeder_full_assembly.stl)**.

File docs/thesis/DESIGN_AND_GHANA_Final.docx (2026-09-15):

GHANA COMMUNICATION TECHNOLOGY UNIVERSITY

(GCTU)

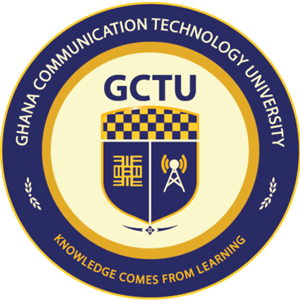
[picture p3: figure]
Home | GCTU_LMS

FACULTY OF ENGINEERING

DEPARTMENT OF COMPUTER ENGINEERING

DESIGN AND DEVELOPMENT OF AN AUTONOMOUS ROVER FOR PRECISION SEED PLANTING AND SPOT WATERING ON SMALLHOLDER FARMS

A Project Work Submitted in Partial Fulfillment of the Requirements For

BSc Computer Engineering

BY:

ELIKPLIM KOFI NYAHE – 4121230028

AARON LORD ANNAN – 1706202763

SUPERVISOR:

DR. SAMUEL DANSO

JUNE, 2026

# TABLE OF CONTENTS

# TABLE OF TABLES

# TABLE OF FIGURES

# CHAPTER ONE

# INTRODUCTION

## 1.1 Background to the Study

In Ghana and across much of sub-Saharan Africa, smallholder farmers form the backbone of food production. They cultivate relatively small plots of land, often relying on family labour and basic hand tools to carry out planting and watering tasks. Despite their central role in feeding the population, these farmers face persistent challenges that limit how much food they can produce from the land available to them. Two of the most significant of these challenges are the inconsistency of manual seed planting and the inefficiency of traditional irrigation methods [1], [2].

The scale of dependence on smallholder agriculture in Ghana is substantial, as summarised in Table 1.1. Agriculture accounts for approximately 23% of the national Gross Domestic Product (GDP) and employs over 52% of the labour force, while providing over 90% of the country’s food needs [31]. The vast majority of this production comes from smallholder farmers using traditional methods: about 60% of all farm holdings are less than 1.2 hectares in size, and small-to-medium farms of up to 10 hectares account for 95% of cultivated land [31], [32]. The predominant farming system remains traditional, involving the use of hoe and cutlass, with mechanised farming being minimal [32]. Perhaps most critically, less than 3% of cultivated land is under any form of irrigation, meaning that over 90% of food production is entirely rain-fed [33], [34].

Indicator | Value
Contribution of agriculture to GDP | ~23%
Share of labour force in agriculture | >52%
Proportion of food needs met domestically | >90%
Farm holdings under 2 hectares | ~60%
Small/medium farms (≤10 ha) share of cultivated land | 95%
Predominant farming system | Traditional (hoe and cutlass)
Irrigated area as share of cultivated land | <3%
Total area equipped for irrigation (est.) | ~59,000 ha

Table 1. 1: Key Indicators of Ghana's Agricultural Sector

Source: Compiled from FAO [31]; MoFA/SRID [32]; FAO AQUASTAT [33]; Dittoh [34].

Of all the stages involved in growing a crop, the planting stage has an outsized influence on the final harvest. How seeds are placed into the ground the distance between them, how deep they go, and how evenly they are spread shapes the entire trajectory of the crop from germination through to maturity. On most smallholder farms in Ghana, seeds are planted by hand, either through broadcasting (scattering seeds across the soil surface) or dibbling (poking holes individually and dropping seeds in). Both approaches introduce a high degree of variability. It is practically impossible for a person to maintain perfectly even spacing and consistent depth over hundreds or thousands of planting points across a field. What happens as a result is that some seeds end up too close together, forcing the emerging seedlings to compete intensely for sunlight, water, and soil nutrients. Meanwhile, gaps form in other parts of the field where seeds were missed or spaced too far apart, leaving productive land unused. Seeds placed too shallow may dry out before they can germinate, and those pushed too deep may struggle to reach the surface. The overall effect is an uneven crop stand some areas are overcrowded, other areas are bare, and plants mature at different rates, which complicates weeding, fertiliser application, and harvesting.

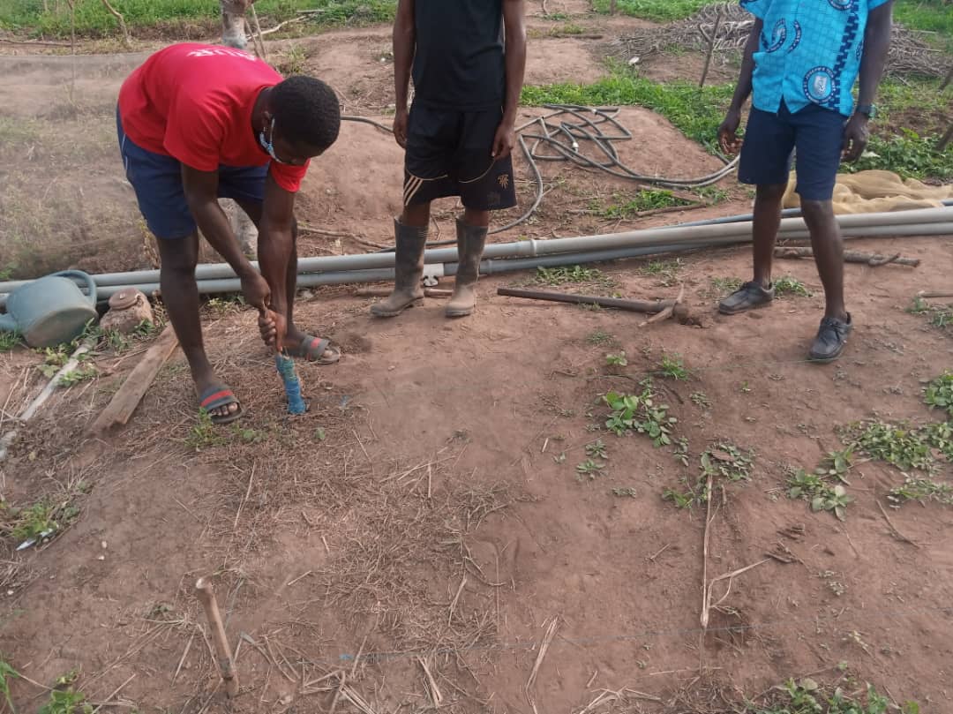
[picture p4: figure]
Students planting seeds manually on a smallholder farm in Ghana

Figure 1. 1 Manual seed planting on a smallholder farm in Ghana

The consequences of these inefficiencies are compounded by losses throughout the food supply chain. According to the Food and Agriculture Organization (FAO), as much as 37% of all food produced in sub-Saharan Africa is lost between production and consumption [35]. For cereal crops specifically, the African Postharvest Losses Information System (APHLIS) estimates annual post-harvest losses in the range of 9–18%, while studies on maize the most important staple for resource-poor smallholders in Africa report grain losses of between 14% and 36% [36], [37]. The economic value of post-harvest grain losses alone in sub-Saharan Africa has been estimated at $4 billion per year, an amount sufficient to meet the annual food needs of over 40 million people [35], [38]. These figures are summarised in Table 1.2.

Loss Category | Estimated Range | Source
Total food lost (production to consumption), SSA | ~37% | FAO (2011)
Post-harvest cereal losses, SSA | 9–18% | APHLIS
Post-harvest maize grain losses, Africa | 14–36% | Tefera (2012)
Economic value of grain PHL in SSA | $4 billion/year | FAO (2011)
Post-harvest mango losses, Ghana | ~49% | Moneda Africa (2025)

Table 1. 2 Estimated Food Losses in Sub-Saharan Africa

Source: Compiled from FAO [35]; APHLIS; Tefera [36]; World Bank [37]; Moneda Africa [38].

While a substantial portion of these losses occurs after harvest (during storage and transport), the losses that begin at the planting stage through poor germination caused by inconsistent seed placement and inadequate initial watering are often overlooked. Improving the precision of planting and initial irrigation thus represents an upstream intervention that can reduce the cascade of losses that follows.

Precision seed dispensing tackles the planting problem directly. The idea is straightforward: instead of relying on a human hand to scatter or drop seeds, a mechanical or electromechanical dispensing system releases individual seeds at programmed intervals and at a controlled depth as it moves along the planting row. The result, at least in principle, is that every seed gets roughly the same amount of space and the same starting conditions, which gives every plant in the field a more equal chance of reaching its full yield potential. As Table 1.3 illustrates, the performance gap between manual and automated sowing approaches is significant across multiple parameters.

Parameter | Manual Sowing | Automated/Robotic
Seed spacing consistency | Highly variable | Uniform (±2 mm)
Planting depth control | Inconsistent | Programmable (e.g. 15 mm)
Seed wastage rate | High (broadcasting) | Minimal (metered)
Seeds planted per hour | 10–21 | 50–95
Labour intensity | Very high | Low (autonomous)
Watering integration | Separate manual task | Combined on same pass
Cost trend over 9 months | $18,000 cumulative | $9,000 cumulative

Table 1. 3: Comparison of Manual versus Automated Seed Sowing Performance

Source: Compiled from Nyahe and Annan (this study); Urkude et al. [22]; Srivastava et al. [23].

Research by Heppner et al. [43] provides further empirical evidence for the yield benefits of precise seed placement. In a field study comparing a precision planter to an air drill for corn, the planter achieved a 5.5% higher yield (11,032 kg/ha versus 10,458 kg/ha) due to shallower and more uniform seeding depth (44.8 mm versus 52.4 mm) and a 56% faster speed of emergence (2.5 versus 1.6 plants/day/m²). As shown in Figure 1.2, yield was found to have a positive linear relationship with speed of emergence (R² = 0.38), confirming that uniform and rapid seedling emergence which is a direct consequence of consistent seed placement translates into measurably higher crop output.

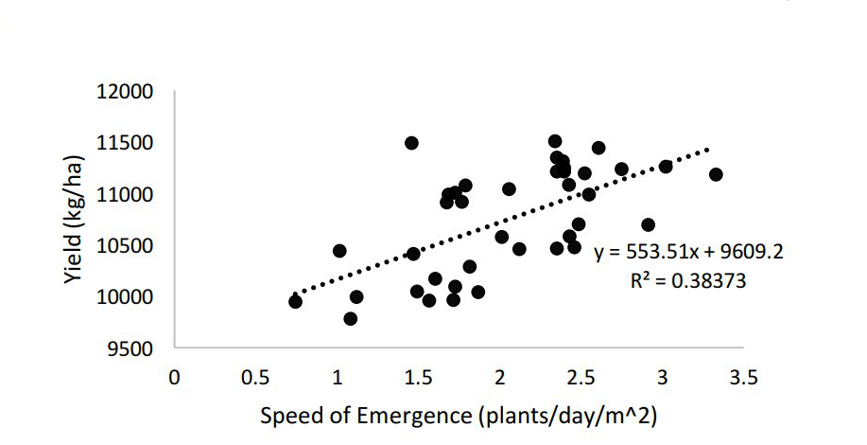
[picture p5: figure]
Scatter plot showing positive linear relationship between speed of emergence and corn yield

Figure 1. 2: Relationship between speed of emergence and corn yield (Heppner et al. [43])

But getting the seed into the ground properly is only half the equation. The other half is water. A seed needs adequate soil moisture to begin the germination process without it, the seed simply sits dormant or dies. In many parts of Ghana, rainfall patterns are seasonal and increasingly erratic due to climate variability, and most smallholder farmers do not have access to mechanised irrigation systems. Where irrigation does happen, it tends to be crude: buckets, hoses, or simple flood methods that apply water broadly across the field without much regard for where it is actually needed. This wastes water on areas that may already be sufficiently moist while leaving drier spots under-served. As noted by the FAO, water use efficiency at both conveyance and field levels in Ghana’s existing irrigation systems is low, since no concerted efforts have been made to address water losses [33]. Targeted spot watering offers a smarter alternative. Rather than flooding the whole field, a spot watering system delivers a controlled amount of water to each individual planting location. If this delivery is guided by an actual measurement of the soil moisture at that specific point, then water only goes where it is genuinely needed, and none is wasted on already-wet soil.

When precision seed dispensing and targeted spot watering are combined on a single platform, the benefits compound. Each seed is placed at the right spacing and depth, and then immediately receives the right amount of water for germination no more, no less. The result is a field of seedlings that emerge uniformly, grow at similar rates, and compete less with each other. This kind of uniformity does not just improve yield; it also makes every subsequent farming operation easier. Weeding is simpler when plants are in straight, evenly spaced rows. Fertiliser can be applied more efficiently. Harvesting is more predictable. For a smallholder farmer working with limited land, limited water, and limited labour, these are not marginal improvements they can make a real difference to household food security and income.

Precision agriculture is the broader field that encompasses these kinds of targeted, data-driven farming interventions. The fundamental idea behind precision agriculture is to apply the right input, in the right amount, at the right place, at the right time. Over the past two decades, research in this area has produced a wide range of technologies variable-rate applicators, remote sensing platforms, automated guidance systems that have proven effective in large-scale commercial farming. Ghalazman et al. [3] reviewed the state of autonomous robots and solar energy systems for precision agriculture and smart farming, noting that while commercially available precision farming tools have become quite advanced, most of them are designed for large operations with substantial budgets. Their analysis made clear that practical, affordable precision agriculture solutions for smallholder farmers are still lacking.

The global precision farming market underscores both the opportunity and the problem. As shown in Table 1.4, the market is projected to grow from approximately $11–15 billion in 2025 to $21–27 billion by 2030, with compound annual growth rates consistently above 9% [39], [40], [41], [42]. However, the vast majority of this market activity is concentrated in North America and Europe, where large-scale commercial farms can justify the cost of advanced GPS guidance systems, AI-enabled analytics, and variable-rate machinery. The Asia-Pacific region is the fastest-growing segment, driven by government modernisation initiatives, but sub-Saharan Africa remains largely absent from these projections. This gap is precisely what motivates the present study: the need for precision agriculture solutions that are designed from the outset for the scale, cost constraints, and infrastructure realities of smallholder farming in Ghana.

Source | 2025 (USD Bn) | 2030 (USD Bn) | CAGR
Grand View Research | $11.67 | $24.09 | 13.1%
MarketsandMarkets | $11.38 | $21.45* | 9.5%
BCC Research | $12.80 | $21.20 | 10.6%
Mordor Intelligence | $14.77 | $26.86 | 12.7%

Figure 1. 3: Global Precision Farming Market Projections (2025–2030)

Source: Compiled from Grand View Research [39]; MarketsandMarkets [40]; BCC Research [41]; Mordor Intelligence [42]. *MarketsandMarkets projects to 2032.

One of the most promising avenues for bringing precision agriculture down to the smallholder scale is through agricultural robotics, and specifically through autonomous ground rovers. A rover is a mobile robotic platform that can travel across a field and carry out tasks planting seeds, spraying water, collecting sensor data with a level of consistency that human hands simply cannot match over a full day of work. Xu and Li [4] built and demonstrated a system they called MARS (Modular Agricultural Robotic System), which used interchangeable hardware modules to perform different farming tasks including plant phenotyping and soil sensing. Their approach showed that a single robotic platform could serve multiple purposes if designed with modularity in mind. Iqbal et al. [5] took a similar path with their MARIA robot, an open-source differential-drive platform that could navigate autonomously both indoors and outdoors while conducting plant monitoring and soil measurements. Both systems proved that integrating multiple agricultural functions onto one robot is technically feasible. That said, neither MARS nor MARIA combined seed dispensing with irrigation on the same rover those remained separate concerns in their designs.

The problem with most of these research-grade agricultural robots is their cost. Systems like MARS and MARIA, while clever in their design, still rely on components and computing platforms that put them out of reach for a typical Ghanaian smallholder farmer. Many agricultural robots in the literature use LiDAR sensors for navigation, which alone can cost more than an entire smallholder farm earns in a year. Others run their software on powerful single-board computers or laptops, which add both cost and complexity. This gap between what is technically possible and what is practically affordable is not trivial [6], [7]. It is especially frustrating because the farmers who would benefit most from automated seed dispensing and spot watering those with the most inconsistent manual planting and the least access to irrigation are exactly the ones who cannot afford the existing systems.

Researchers have explored lower-cost approaches to seed planting automation. Pandey et al. [8] built an AgriBot aimed at small landholdings, using a simple mechanical cam-based seed dropping mechanism. It managed consistent spacing of about 15 cm during trials, but it had no electronic feedback for controlling planting depth and no ability to water the seeds after placement. Debnath et al. [9] developed a smart seed dispenser on a mobile vehicle that could plow, sow, and level the soil, but the vehicle had to be controlled via mobile phone rather than navigating on its own. Ha-mim et al. [10] took an IoT approach, combining Arduino-based seed dispensing with soil moisture sensors and cloud-based monitoring. Their system showed that cheap sensors could provide useful soil data alongside planting, but the robot still needed a human operator to guide it through the field. What all of these projects have in common is that they treat seed dispensing as a standalone task. None of them coupled the dispensing mechanism with autonomous navigation to systematically cover a field, and none of them delivered water to the planting location immediately after seed placement.

For a planting rover to operate without constant human guidance, it needs some form of autonomous navigation. The literature offers a range of approaches at different price points. At the high end, Rakun and Popič [11], [12] built and refined an autonomous navigation algorithm for a robot called FarmBeast, which used LiDAR and IMU sensors together with advanced filtering to generate 3D point clouds for navigating between maize rows. At the affordable end, Kanagasingham et al. [13] got a weeding robot to navigate rice paddies autonomously using a combination of a front-mounted camera for detecting crop rows and GPS plus a compass for handling turns between rows. Levoir et al. [14] looked specifically at making GPS more accurate for rovers without paying for expensive RTK corrections. These studies point toward GPS and IMU as a practical navigation foundation for a low-cost rover not as precise as LiDAR, but workable and dramatically cheaper.

On the software side, the Robot Operating System 2 (ROS 2) has established itself as a go-to framework for building modular robotic systems. Fang et al. [15] used ROS 2 alongside a distributed network of ESP32 microcontrollers for their irrigation robot. Sani et al. [16] worked on improving the ROS 2 navigation stack for outdoor agricultural use. Post et al. [18], [19] built affordable farm robots with off-the-shelf parts running ROS on budget hardware and documented some of the real-world headaches, like GPS drift under tree cover and the computational limits of cheap single-board computers.

A recurring issue in these ROS-based projects is that the framework assumes the computer running it will be available and stable throughout the robot’s operation. On a smallholder farm where power supply may be inconsistent, where the robot might be working in dusty or hot conditions, and where there is no IT support if the software crashes, that assumption becomes risky. This dual-mode architecture ROS 2 on the desktop for design work, a single Arduino-class microcontroller on the rover for actual field operation could offer the best of both worlds, but it remains underexplored in the context of agricultural robots.

This study aims to fill that gap. The rover being developed here is, at its core, a seed dispensing and spot watering machine. The seed dispensing mechanism places individual seeds at controlled spacing and depth as the rover moves along predefined planting rows. The spot watering subsystem delivers a measured amount of water to each planting location right after the seed goes in, but only if a soil moisture reading taken at that point indicates the soil is too dry. For navigation, the rover uses GPS and IMU to follow predefined paths. The software is developed and tested in ROS 2 on a computer, but the rover itself runs on embedded microcontroller firmware (a single Arduino Uno R4) so it does not need a laptop or ROS 2 running in the field.

## 1.2 Statement of the Problem

The fundamental problem addressed by this study is the gap between the precision that smallholder crop production demands and the precision that manual methods can deliver. On Ghanaian smallholder farms, seeds are planted by hand through broadcasting or dibbling, methods that produce wide variations in seed spacing, planting depth, and field coverage. These variations directly reduce germination rates and lead to uneven crop stands, ultimately resulting in a harvest that falls short of what the land and the crop variety could have produced [1], [2].

The water situation compounds the problem. Where farmers rely on bucket irrigation, hosepipes, or simple flood methods, water is distributed unevenly. Some planting locations get soaked while others especially on slightly raised ground or at field edges get too little. Since water is often the most limiting resource for smallholder crop production in Ghana, this inefficiency has real consequences. Seeds in under-watered spots fail to germinate. Water applied to already-moist areas is effectively wasted through runoff or deep percolation.

The core issue is not that farmers lack good seed varieties or suitable land. It is that the manual methods used to place seeds and deliver water introduce too much variability at the most critical stage of crop development. Mechanised precision seed dispensing and soil moisture-informed spot watering could address this variability directly, improving germination rates and water use efficiency without requiring additional land, new crop varieties, or expensive chemical inputs.

Precision agriculture technologies and agricultural robotics have shown they can deliver this kind of consistency [3], [4], [5]. The problem is that most existing systems are built for large-scale farms and come with price tags to match. They tend to rely on LiDAR sensors, powerful computing platforms, and complex software stacks [11], [12], [16] none of which are realistic for a Ghanaian smallholder context. There is also the issue of fragmentation. Most robotic systems in the literature treat seed planting, irrigation, and soil sensing as separate problems to be solved by separate machines [8], [9], [10], [15]. The potential gains from doing both on the same platform, in the same pass over the field, remain largely untapped. On top of this, while the ROS 2 framework is excellent for robot development and simulation, its reliance on continuous middleware availability makes it risky as a runtime system for rovers operating in field conditions where power and computing reliability are uncertain [18], [19].

What is needed, then, is an affordable autonomous rover that brings precision seed dispensing and soil moisture-informed spot watering together on a single platform. It should use low-cost GPS and IMU for navigation, embedded microcontrollers for reliable field operation, and benefit from ROS 2 during the design and testing phase without depending on it in the field.

## 1.3 Objectives of the Study

General Objective

The overall aim of this study is to design and build an autonomous rover for precision seed planting and spot watering on smallholder farms in Ghana, using GPS and IMU-based navigation, embedded microcontroller control, and a ROS 2-supported development process.

Specific Objectives

The specific objectives are to:

1. Design and build a low-cost rover platform that integrates mechanisms for precision seed dispensing of 3 seeds per hole and targeted spot watering.

2. Develop a GPS and IMU-based navigation system that enables the rover to follow predefined planting rows autonomously.

3. Incorporate soil moisture sensing so that spot watering decisions at each planting point are based on actual soil conditions rather than a fixed schedule.

4. Implement a dual-mode software approach where ROS 2 is used for development, simulation, and testing, while embedded microcontroller firmware handles standalone field operation.

5. Test and evaluate the rover through simulation and controlled field trials, measuring navigation accuracy, seed placement consistency, watering precision, and overall system reliability.

## 1.4 Significance of the Study

On the practical side, this project addresses a real need. Smallholder farmers in Ghana and similar contexts would benefit from a machine that can plant seeds evenly and deliver water precisely, because these are exactly the tasks where manual methods fall short and where small improvements can lead to meaningful gains in yield and water efficiency. The rover is designed to be affordable enough that it could realistically be used at the community level, even if individual ownership might remain out of reach for most farmers initially. By prioritising low-cost components and embedded control, the design avoids the trap of building a technically impressive system that no one in the target context can actually afford or maintain. Ghalazman et al. [3] made a strong case that solar-powered autonomous robots represent a sustainable direction for precision agriculture in resource-limited settings, and this project aligns with that direction by keeping energy consumption and component costs low.

From an academic perspective, the project makes a contribution by showing how a functional agricultural robot can be designed under tight cost and resource constraints. The dual-mode architecture using ROS 2 for development but embedded firmware for field deployment is a practical pattern that other student projects and research groups could adopt. It offers the modelling and simulation benefits of a modern robotic framework without the reliability headaches of running that framework on a rover in the field. The integration of seed dispensing, spot watering, and soil moisture sensing on a single low-cost platform also addresses a gap that runs through the literature, where these functions are almost always implemented on separate systems [4], [5], [8], [9], [10].

## 1.5 Scope of the Study

This study covers the design, construction, and initial evaluation of an autonomous rover for precision seed planting and spot watering in smallholder farm settings. The work includes mechanical design (the chassis, drive system, seed dispensing mechanism, and water delivery system), electronics integration (microcontrollers, motor drivers, sensors, and power supply), and software development for navigation and task control.

The rover’s navigation relies on GPS and IMU data for position and heading. LiDAR, SLAM, and advanced obstacle avoidance are not part of the current design due to their cost. An ESP32-CAM module may be explored for basic visual assistance, but camera-based navigation is not a core design requirement.

ROS 2 is used for simulation, algorithm testing, and system integration on a desktop or laptop computer. The rover itself runs on embedded firmware (a single Arduino Uno R4) and does not require ROS 2 to be running during field operation.

Testing takes place in controlled environments with relatively flat, uniform terrain. The project assesses baseline functionality and reliability, not full commercial readiness. The seed dispensing mechanism is designed for small to medium seed types like maize, beans or groundnuts, and the water delivery system is sized for the modest volumes appropriate to smallholder plot sizes.

## 1.6 Research Questions

This study seeks to answer the following questions:

1. How accurately can GPS and IMU-based navigation guide the rover along predefined planting paths in conditions typical of Ghanaian smallholder fields?

2. How consistently can the rover achieve target seed spacing and water delivery volumes using its low-cost dispensing and pumping mechanisms? Planting depth control was descoped from this study because of time constraints and is treated as future work in Chapter Five.

3. Does integrating real-time soil moisture sensing improve spot watering efficiency compared to applying a fixed amount of water at every planting point?

4. How does the reliability of the embedded microcontroller-based field operation compare to what is achieved in the ROS 2 simulation and testing environment?

## 1.7 Methodology Overview

The project follows a modular development methodology. The rover's hardware and software are organised into six functional modules, Core Processing and Communication, Power Management and Failsafe, Locomotion and Motor Protection, Sensor and Navigation, Actuators and Payload, and Telemetry and Visualisation, each specified, built, and bench-tested largely on its own before being integrated into the complete system. Splitting the work this way kept faults easier to isolate during assembly, since a problem could usually be traced to a single module rather than the system as a whole. Within that structure, individual modules still went through their own rounds of revision as components were swapped or issues were found during integration, as described in the relevant sections of Chapter Three. The key metrics for evaluation include navigation path deviation, seed spacing accuracy, water delivery precision, and system reliability across the two operating modes. Full design details, implementation steps, and test protocols are presented in Chapter Three.

Figure 1.3 illustrates the generic form of a modular development methodology, before it is applied to this specific project: a system is decomposed into independent modules, each of which is designed, built, and tested largely on its own, before the modules are integrated and the complete system is tested against its requirements.

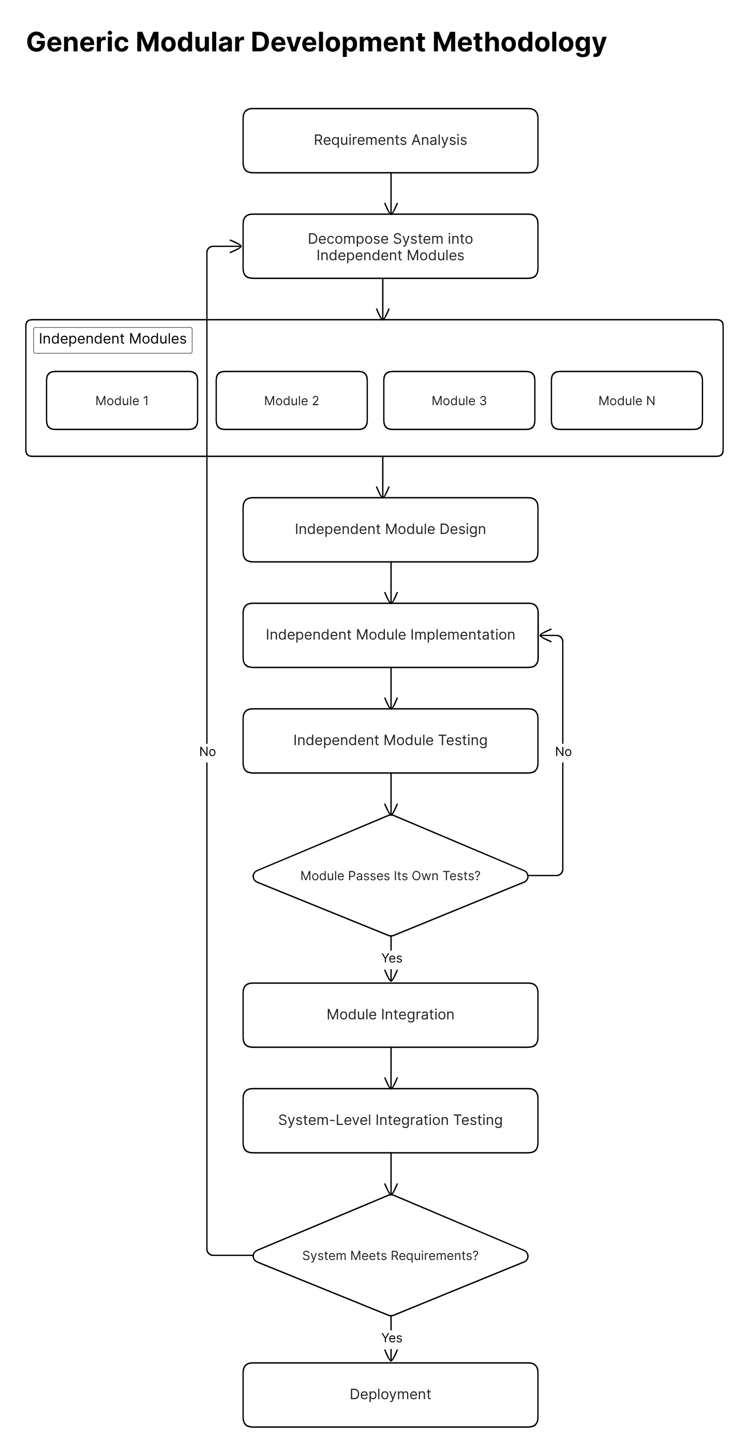
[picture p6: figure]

Figure 1. 1 Generic modular development methodology

Figure 1.4 shows this same methodology applied to the present project, with the six functional modules named in place of the generic "Module 1" through "Module N" placeholders, and the design-build-bench test loop applied independently to each one before integration onto the rover chassis.

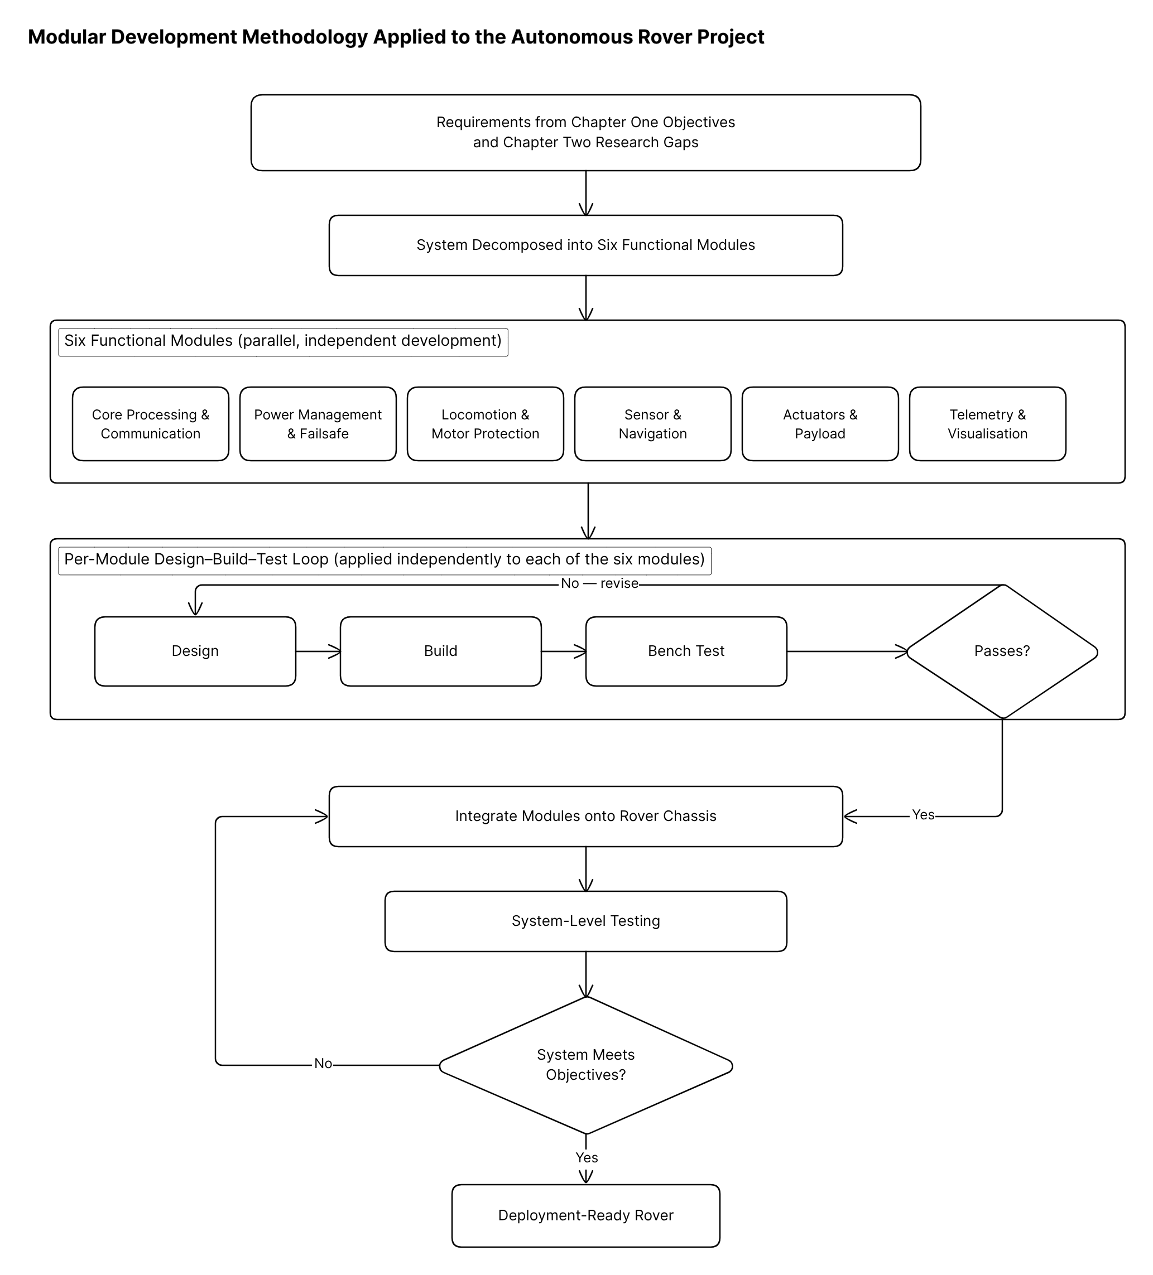
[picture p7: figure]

Figure 1. 1 Modular development methodology as applied to this project

## 1.8 Operational Definitions

Autonomous rover: A mobile robotic platform that can move across a field and carry out specified tasks (in this case, seed planting and spot watering) without needing continuous human control during operation.

Precision seed dispensing: Placing individual seeds at set spacing intervals to promote even germination and crop emergence across the field. Depth control was not implemented in this study and is treated as future work.

Spot watering: Delivering a measured quantity of water to a specific planting location rather than irrigating the whole field uniformly. In this study, spot watering decisions are guided by soil moisture readings at each planting point.

ROS 2-enabled development: Using the Robot Operating System 2 framework for writing, simulating, and testing the rover’s software, without requiring ROS 2 to run on the rover during actual field deployment.

Standalone (embedded) mode: The rover running its navigation and task-execution functions on microcontroller firmware (a single Arduino Uno R4) independently of ROS 2.

Differential drive: A drive configuration with two independently powered wheels, allowing the rover to move forward, turn, and rotate in place by varying the speed of each wheel.

## 1.9 Organisation of the Report

This report is organised into five chapters. Chapter One introduces the study with its background, problem statement, objectives, significance, scope, and research questions. Chapter Two reviews the relevant literature on agricultural robotics, precision seed planting, navigation techniques, spot watering and irrigation, soil sensing, and ROS/ROS 2-based systems. Chapter Three covers the system design, hardware selection, circuit design, software architecture, and implementation details. Chapter Four presents and discusses the results from simulation and field testing. Chapter Five concludes with a summary of findings, limitations of the study, and recommendations for future work.

# CHAPTER TWO

# LITERATURE REVIEW

## 2.1 Introduction

This chapter reviews existing research related to the design and development of autonomous agricultural robots, focusing on five key areas: precision seed planting mechanisms, autonomous navigation techniques, spot watering and precision irrigation, soil sensing in farming robots, and ROS/ROS 2-based robotic systems. The literature drawn upon consists mainly of peer-reviewed journal papers, conference proceedings, and technical reports published between 2017 and 2026, chosen to capture both established foundations and the most recent work in the field.

The review has three purposes. The first is to establish what has already been achieved in agricultural robotics and precision farming technology what kinds of systems exist, what approaches they use, and how well they perform. The second is to critically examine the strengths and weaknesses of these existing systems, paying particular attention to cost, complexity, the degree to which different functions are integrated on a single platform, and suitability for smallholder farming environments in developing countries. The third purpose is to identify the specific research gaps that justify the design choices made in this study.

The chapter is divided into six thematic sections. After this introduction, Section 2.2 covers the broader landscape of precision agriculture and agricultural robotics. Sections 2.3 through 2.6 address the four main technical areas seed planting, navigation, irrigation, and soil sensing in turn. Section 2.7 discusses ROS and ROS 2-based systems. The chapter concludes with a comparative summary table (Table 2.1) and a discussion of the identified research gaps.

## 2.2 Precision Agriculture and Agricultural Robotics

Precision agriculture, broadly defined, is about applying the right farming inputs in the right amounts at the right locations and times. Instead of treating an entire field uniformly, precision agriculture uses data from sensors, GPS, cameras, or other sources to tailor operations to the actual conditions at each point in the field. When applied to planting and irrigation, this means placing each seed where it will grow best and delivering water only where it is actually needed. The integration of robotic systems into this approach offers the possibility of carrying out these tasks with a consistency and accuracy that manual labour cannot sustain over a full working day.

Ghalazman et al. [3] carried out a wide-ranging review of autonomous robots and solar energy applications in precision agriculture. Their paper examined the current state of robotic platforms for farming, their energy needs, and the potential for solar power to make these systems more sustainable. A key takeaway from their analysis was that while agricultural robots have become quite sophisticated in research and commercial settings, the vast majority of them are designed for large-scale operations. The cost of entry, both in terms of hardware and the technical knowledge required to operate these systems, puts them out of reach for most smallholder farmers.

Xu and Li [4] took a different approach with their Modular Agricultural Robotic System, or MARS. The central idea behind MARS was modularity: the robot was built from five core hardware modules and three optional ones. By swapping and combining modules, a single platform could be reconfigured for different tasks, from plant phenotyping to soil sensing. The limitation, from the perspective of this study, is that MARS was developed and tested at the University of Georgia a well-resourced research environment quite different from the conditions on a Ghanaian smallholder farm.

Iqbal et al. [5] developed MARIA, short for Multipurpose Autonomous Robot of Intelligent Agriculture. MARIA was an open-source differential-drive robot that navigated outdoors using GPS waypoints and indoors using LiDAR. The open-source approach was commendable and made the design accessible to other researchers, but MARIA required a laptop running ROS to function, which raised concerns about field reliability and power consumption.

Zinzani et al. [20] introduced Rockerbot, a compact rover built for navigating maize crop rows during early growth stages. The rover used a rocker-bogie suspension borrowed from planetary rover designs, which helped it maintain stability on uneven agricultural terrain. It was designed for monitoring rather than planting or watering, so it did not address the specific tasks this study targets.

Menon and Prabhakar [21] developed a Smart Agriculture Monitoring Rover aimed at small-scale farms in rural areas. Built around an Arduino Mega, their system monitored weather and soil conditions using IoT sensors and included a sprinkler mechanism for water delivery and pest treatment. The rover was not autonomous it required manual or remote control and the sprinkler applied water broadly rather than to specific planting points.

Taken together, these studies paint a picture of a field that has made substantial technical progress but still has a significant gap when it comes to affordable, multi-function autonomous rovers for smallholder farming. Systems that are sophisticated enough to combine seed dispensing, spot watering, and autonomous navigation tend to be too expensive. Systems that are cheap enough for smallholder contexts tend to sacrifice either autonomy, precision, or the integration of multiple functions. Bridging this gap is the central motivation for the present study.

## 2.3 Precision Seed Planting Mechanisms

Getting seeds into the ground at consistent spacing and depth is one of the most impactful things a farmer can do to improve crop performance. When spacing and depth are controlled, plants emerge more uniformly, compete less with each other, and ultimately yield more.

Pandey et al. [8] built an AgriBot specifically for farmers with small landholdings who could not afford commercial planting equipment. The AgriBot used a mechanical cam mechanism driven by the rotation of the wheels to drop seeds at regular intervals, achieving roughly 15 cm spacing. The simplicity of the cam-based approach meant it was cheap and mechanically robust, but it also meant there was no electronic control over planting depth and no way to adjust spacing on the fly.

Debnath et al. [9] designed a smart seed dispenser, mounted on a small vehicle that could plow, sow, and level the soil in a single pass. The dispensing mechanism used a servo motor to release seeds at programmed intervals. The main limitation was that the vehicle required a human operator controlling it via a mobile phone.

Ha-mim et al. [10] integrated seed dispensing with IoT-based soil monitoring in an Arduino-controlled system. The IoT aspect was a genuine step forward in terms of making soil data available alongside planting. However, the system was manually guided and did not have any path planning or autonomous navigation capability.

Urkude et al. [22] built a simpler seed dispenser around an Arduino Uno with a servo-controlled mechanism and a soil sensor. They tested it on different soil types and reported consistent performance. However, the device was a standalone dispenser it was not mounted on an autonomous mobile platform.

Manimekalai et al. [23] developed an Arduino-based seed sowing robot that combined a robotic arm with a conveyor belt and dispensing mechanism. Their system could also cover seeds with soil and apply water after planting, making it one of the more integrated low-cost designs. The catch was that it navigated using simple line-following, which required black lines to be physically marked on the field beforehand.

Liu et al. [24] conducted a detailed mechanical study of seed dispensers with eye-type metering mechanisms, using discrete element method (DEM) simulation. This kind of engineering analysis is valuable for predicting performance before building a physical prototype, but the study was purely analytical.

Vakiti and Subhadra [25] built a Smart Seed Sower that combined solar power, IoT-based soil monitoring, and a seed dispensing mechanism. It was one of the few low-cost systems that addressed energy sustainability alongside planting. But like several others, it lacked autonomous mobility and did not include an irrigation function.

One project that came closest to the concept pursued in this study was an autonomous farming robot for precision seed sowing and targeted irrigation using wireless control [26]. This system automated hole drilling, seed dispensing, and immediate watering on a single wirelessly controlled platform. The limitation was that it operated under wireless remote control rather than autonomous navigation.

Three observations emerge from this body of literature. First, low-cost seed dispensing systems based on microcontrollers and simple mechanical designs can achieve acceptable planting consistency. Second, almost all existing systems treat seed dispensing in isolation. Third, the step from manually guided or remote-controlled planting to fully autonomous operation on a budget remains an open challenge. This study addresses all three points.

## 2.4 Navigation Techniques for Agricultural Robots

For a planting rover to work without a human steering it, it needs to know where it is and where it is going. The quality of navigation directly affects the quality of the planting.

At the expensive end, Rakun and Popič [11], [12] developed an autonomous navigation system for the FarmBeast robot using LiDAR combined with an IMU and advanced data filtering. Their improved algorithm reduced traversal time by up to 33% and crop damage by 25%, but at the cost of expensive LiDAR hardware.

Sperti et al. [27] went in a different direction with a non-linear model predictive control (NMPC) system for GPS-free navigation in vineyards. The approach was clever and cost-effective on the sensor side, but NMPC is computationally demanding and the system depended on visible crop rows for guidance.

Sani et al. [16] tackled a specific problem with the ROS 2 Nav2 navigation stack: in agricultural settings, the standard obstacle detection treats tall grass and weeds as impassable barriers. Their solution used a depth camera with pixel-level classification to update the navigation costmap in real time.

Vu et al. [17] built a ROS 2-based navigation system for orchard robots using RTK-GNSS, stereo cameras, visual odometry, and IMU fusion. However, the sensor suite puts the total cost well above what this study is targeting.

On the more affordable side, Kanagasingham et al. [13] achieved fully autonomous navigation for a rice field weeding robot by combining camera-based crop row detection with GPS and compass data. Levoir et al. [14] focused specifically on making GPS more accurate without paying for RTK equipment. Their results showed that with the right signal processing, cheap GPS can be good enough for many precision agriculture tasks.

Shi et al. [28] published a thorough review of row detection-based navigation methods for agricultural robots. Their conclusion was practical: the right navigation method depends on the specific application, the crop, the growth stage, and the budget available. Lim and Phang [29] worked on obstacle detection for rovers in plantation settings, training a YOLOv5 model to classify obstacles.

Post et al. [18], [19] are perhaps the most directly relevant to this study. They built autonomous agricultural robots using ROS and inexpensive hardware, and they were honest about the problems they encountered: GPS drifting under tree canopy, single-board computers struggling with computational load, and wireless communication dropping out in the field. These practical lessons strongly influenced the decision in this study to use embedded microcontrollers for field operation.

The navigation literature supports three conclusions for this project. GPS and IMU provide a workable navigation foundation for a low-cost rover operating in open fields. The ROS 2 navigation tools are valuable for development and simulation but need customisation for agricultural use and are risky to depend on in the field. And the choice of navigation method should be driven by practical constraints rather than by chasing maximum accuracy.

## 2.5 Spot Watering and Precision Irrigation Systems

Water is often the most limiting factor for crop production on smallholder farms, particularly in areas with seasonal or erratic rainfall. Delivering water efficiently can make the difference between a successful germination and a failed one.

Fang et al. [15] built one of the more technically advanced irrigation robots in the recent literature. Their system ran on ROS 2 and used a YOLOv8 vision model to detect and locate individual plants, then navigated to each one using LiDAR-based SLAM to deliver water. It was an elegant design, but it was built for indoor houseplants, and its reliance on LiDAR and trained AI models puts it in a different cost bracket.

The autonomous farming robot described in [26] came closer to the concept of this study by integrating seed dispensing with immediate watering on the same platform. The drawback was that the robot was wirelessly remote-controlled and did not use soil moisture data to decide how much water to deliver.

Menon and Prabhakar [21] included a sprinkler system on their monitoring rover, capable of spraying water over a general area. This is useful for broad-area treatment but lacks the precision needed for spot watering.

Sathya et al. [30] built an Intelligent Agritech Rover that collected soil data and applied machine learning to predict crop suitability and irrigation requirements. The concept of using rover-collected soil data to inform watering decisions is directly relevant to this study’s approach.

Two trends stand out from the irrigation literature. First, the most effective precision irrigation systems base their water delivery decisions on actual measured conditions rather than on fixed schedules. Second, the integration of irrigation with planting on a single autonomous platform is still rare. This study addresses both points.

## 2.6 Soil Sensing in Autonomous Farming Systems

Soil moisture measurement is the sensing function most directly relevant to this study, because it provides the data that determines whether and how much water the rover delivers at each planting point.

Iqbal et al. [5] included soil sensing on the MARIA platform, using penetrometer measurements alongside plant phenotyping sensors. Ha-mim et al. [10] used soil sensors in their IoT-based seed sowing system for monitoring and cloud upload. They demonstrated that inexpensive capacitive soil moisture sensors provide readings that are reliable enough for practical irrigation decisions when properly calibrated. Vakiti and Subhadra [25] put IoT-enabled soil sensors on their Smart Seed Sower, measuring humidity, pH, temperature, and nutrients. Sathya et al. [30] used their rover to collect soil moisture, potassium, phosphorus, and nitrogen data, feeding it into machine learning models.

The pattern across these studies is clear: researchers have demonstrated that low-cost soil sensors mounted on rovers can collect useful data, and that this data can inform irrigation decisions. What has not been widely demonstrated is the closing of the control loop on the rover itself using a soil moisture reading taken at a specific planting location to immediately decide, on the spot, whether to pump water to that location. This is what the present study implements: a closed-loop system where the soil moisture sensor feeds directly into the rover’s watering control logic.

## 2.7 ROS and ROS 2-Based Agricultural Robotic Systems

ROS (Robot Operating System) and its successor ROS 2 have become standard tools in robotics research. They provide a publisher-subscriber communication system, a library of ready-made packages for navigation and perception, and simulation environments like Gazebo.

Post et al. [18], [19] used ROS to build affordable farm robots and were candid about what worked and what did not. On the positive side, ROS allowed them to integrate GPS, IMU, and odometry data into a coherent navigation system quickly. On the negative side, they ran into GPS drift, limited processing power on budget single-board computers, and flaky wireless connections during field tests.

Fang et al. [15] used ROS 2 alongside a distributed network of ESP32 microcontrollers. The central computer ran ROS 2 for SLAM, navigation, and high-level decision-making, while the ESP32 nodes handled lower-level tasks. This hybrid architecture is relevant because it shows one way to distribute the workload. The present study takes this idea a step further by having the microcontrollers handle everything in the field.

Sani et al. [16] showed that the ROS 2 Nav2 stack needs custom extensions for agricultural environments. Vu et al. [17] demonstrated the capabilities of a full ROS 2-based navigation system in orchards, but with hardware that costs significantly more than what this project can afford.

The takeaway from the ROS/ROS 2 literature is that ROS 2 is an excellent development tool but a risky field runtime for budget agricultural robots. This dual-mode approach (ROS 2 for design, embedded firmware for deployment) is what the present study adopts.

## 2.8 Summary of Related Works and Research Gaps

Table 2.1 summarises the key works reviewed in this chapter, listing their focus areas, technologies, main contributions, and limitations

Ref. | Author(s) & Year | Focus | Key Technologies | Contributions | Limitations
[3] | Ghalazman et al. (2023) | Autonomous robots and solar energy for precision agriculture | Survey: robotics, solar energy | Comprehensive review of robotic platforms and energy solutions | Review paper; no system built
[4] | Xu and Li (2022) | MARS: Modular Agricultural Robotic System | Modular hardware, ROS, GPS | Multi-purpose platform for phenotyping and farming | Designed for US research context; not smallholder-oriented
[5] | Iqbal et al. (2020) | MARIA: Multi-purpose autonomous robot | ROS, GPS, LiDAR, differential drive | Open-source platform for plant phenotyping and soil sensing | Needs a laptop running ROS; field reliability concerns
[8] | Pandey et al. (2023) | AgriBot for seed sowing automation | Mechanical cam dispenser, DC motors | Low-cost planting for small farms | No depth control; no irrigation or sensing
[9] | Debnath et al. (2024) | Smart seed dispenser | Servo dispenser, mobile phone control | Integrated plowing, sowing, and levelling | Not autonomous; no irrigation
[10] | Ha-mim et al. (2023) | IoT-based seed sowing and nutrition | Arduino, soil sensors, IoT | Seed sowing with soil monitoring | Manually guided; no autonomous navigation
[11],[12] | Rakun and Popič (2025, 2026) | Autonomous navigation for FarmBeast | LiDAR, IMU, sensor fusion, ROS | 33% faster traversal, 25% less crop damage | Requires LiDAR; expensive
[13] | Kanagasingham et al. (2019) | Vision + GPS/compass navigation | Camera, GPS, compass | Fully autonomous weeding robot | Needs visible crop rows; unsuitable for bare-field planting
[14] | Levoir et al. (2020) | Low-cost GPS accuracy improvement | Adaptive GPS, sensor fusion | Better GPS accuracy without RTK | Localisation only; no task integration
[15] | Fang et al. (2024) | ROS 2 irrigation robot | ROS 2, YOLOv8, LiDAR, ESP32 WMN | Vision-based plant detection with irrigation | Indoor application; high sensor costs
[16] | Sani et al. (2024) | ROS 2 Nav2 for agriculture | ROS 2, depth camera, costmap layers | Real-time costmap updates for farm navigation | Requires custom extensions; adds complexity
[17] | Vu et al. (2024) | Orchard navigation with ROS 2 | ROS 2, RTK-GNSS, stereo cameras | Hybrid controller for row following | Expensive hardware (RTK, stereo cameras)
[18],[19] | Post et al. (2017, 2018) | Affordable farm rover with ROS | ROS, GPS, IMU, odometry | Autonomous navigation on a budget | GPS drift under canopy; limited computing
[20] | Zinzani et al. (2024) | Rockerbot for maize farming | GPS, IMU, rocker-bogie suspension | Cost-effective rover for crop row traversal | Monitoring only; no planting or irrigation
[21] | Menon and Prabhakar (2023) | Smart agriculture monitoring rover | Arduino, IoT sensors, sprinkler | IoT monitoring with basic sprinkler | Manual/remote control; broad-area watering
[22] | Urkude et al. (2025) | Arduino-based seed dispenser | Arduino Uno, servo, soil sensor | Uniform seed spacing across soil types | Standalone device; not on a mobile platform
[23] | Manimekalai et al. (2023) | Arduino seed sowing robot | ATmega, conveyor, line following | Combined planting, covering, and watering | Line-following navigation; not GPS-based
[24] | Liu et al. (2024) | Seed dispenser mechanical analysis | DEM simulation, ANSYS | Validated dispensing consistency | Mechanical analysis only; no field test
[25] | Vakiti and Subhadra (2023) | Smart Seed Sower: IoT + solar | Solar panels, IoT soil sensors | Solar-powered dispensing with soil monitoring | No autonomous mobility
[26] | Autonomous Farming Robot (2024) | Seed sowing + targeted irrigation | Wireless control, drill, pump | Integrated drilling, dispensing, and watering | Remote-controlled; no autonomous navigation
[27] | Sperti et al. (2024) | GPS-free vineyard navigation | RGB-D camera, NMPC | Cost-effective row navigation without GPS | Needs existing crop rows; computationally heavy
[28] | Shi et al. (2023) | Row detection navigation review | Survey: cameras, LiDAR, DL | Taxonomy of navigation approaches | Review paper; no implementation
[29] | Lim and Phang (2023) | Obstacle detection for rovers | YOLOv5, camera | Obstacle classification in plantations | Detection only; no task integration
[30] | Sathya et al. (2024) | Intelligent Agritech Rover | ML, soil sensors, rover | Soil quality prediction with machine learning | Monitoring and prediction only; no irrigation

Table 2. 1: Comparative Summary of Related Works

Based on this review, five research gaps stand out:

Gap 1 No affordable multi-function rovers for smallholders. The systems that combine navigation, planting, and irrigation tend to be expensive. The ones that are cheap tend to do only one thing, or require human control. An affordable rover that does all three autonomously does not currently exist in the literature for smallholder contexts.

Gap 2 Seed dispensing and irrigation are not integrated. Planting robots [8], [9], [10], [22], [23] and irrigation systems [15], [21], [26] are developed separately. The efficiency gain from dispensing a seed and immediately watering that exact spot based on measured soil moisture has not been exploited on a single autonomous platform.

Gap 3 GPS/IMU navigation has not been applied to low-cost planting rovers. While GPS and IMU have been used for monitoring and general field traversal [14], [18], [19], [20], their specific application to guiding an autonomous seed dispensing and spot watering rover on a smallholder farm has not been demonstrated.

Gap 4 Soil moisture sensors are used for monitoring, not real-time control. Most systems that include soil sensors use them for data logging and cloud monitoring [10], [21], [25], [30]. Closing the loop using the reading to decide on the spot whether to pump water has not been widely implemented on mobile agricultural platforms.

Gap 5 Dual-mode ROS 2 development with embedded deployment is unexplored. ROS 2 is common in agricultural robotics research [15], [16], [17], and budget rovers have used ROS with acknowledged reliability issues [18], [19]. But systematically using ROS 2 for development and simulation while deploying standalone embedded firmware for field operation has not been explored for smallholder agricultural robots.

This study addresses all five gaps. It develops a low-cost autonomous rover that integrates GPS/IMU navigation, precision seed dispensing, soil moisture sensing, and targeted spot watering on a single platform, using a dual-mode software approach (ROS 2 for development, embedded microcontroller firmware for field deployment), specifically targeting smallholder farming conditions in Ghana.

# CHAPTER THREE

# DESIGN AND SPECIFICATION

## 3.1 Introduction

This chapter presents the design and specification of the autonomous rover developed for this study. It translates the objectives set out in Chapter One and the research gaps identified in Chapter Two into a concrete system architecture, hardware configuration, and software design. The chapter opens with the overall design philosophy and system overview, then works through the mechanical structure, the electronic hardware organised by functional module, the circuit design and pin assignment, the bill of materials, the power budget, and the software and control architecture that ties the whole system together. Design constraints and the trade-offs they forced are discussed at the end of the chapter.

## 3.2 Design Philosophy and System Overview

The overriding design constraint for this project is cost. A rover that performs well but that no smallholder farmer or farmer cooperative in Ghana could realistically afford or repair would not address the problem set out in Chapter One. Every hardware decision in this chapter was therefore made with three questions in mind: can the part be sourced locally or through channels already available to Ghanaian students and technicians, can it be repaired or replaced without specialised tools, and does it add enough capability to justify its cost and complexity. This is the same reasoning that ruled out LiDAR-based navigation and single-board computer control in Chapter Two, and it carries through every subsystem described below.

The rover's hardware and software are organised into six functional modules: Core Processing and Communication, Power Management and Failsafe, Locomotion and Motor Protection, Sensor and Navigation, Actuators and Payload, and Telemetry and Visualisation. Organising the system this way keeps each concern separable during development and testing, and it maps cleanly onto the six subsections used later in this chapter to describe the electronic hardware. Figure 3.1 shows how the modules relate to one another and to the rover's two operating modes, autonomous mission mode and manual teleoperation. Figure 3.9, at the end of this chapter, gives the complementary deployment view of the same system once the cloud and companion application tiers are included.

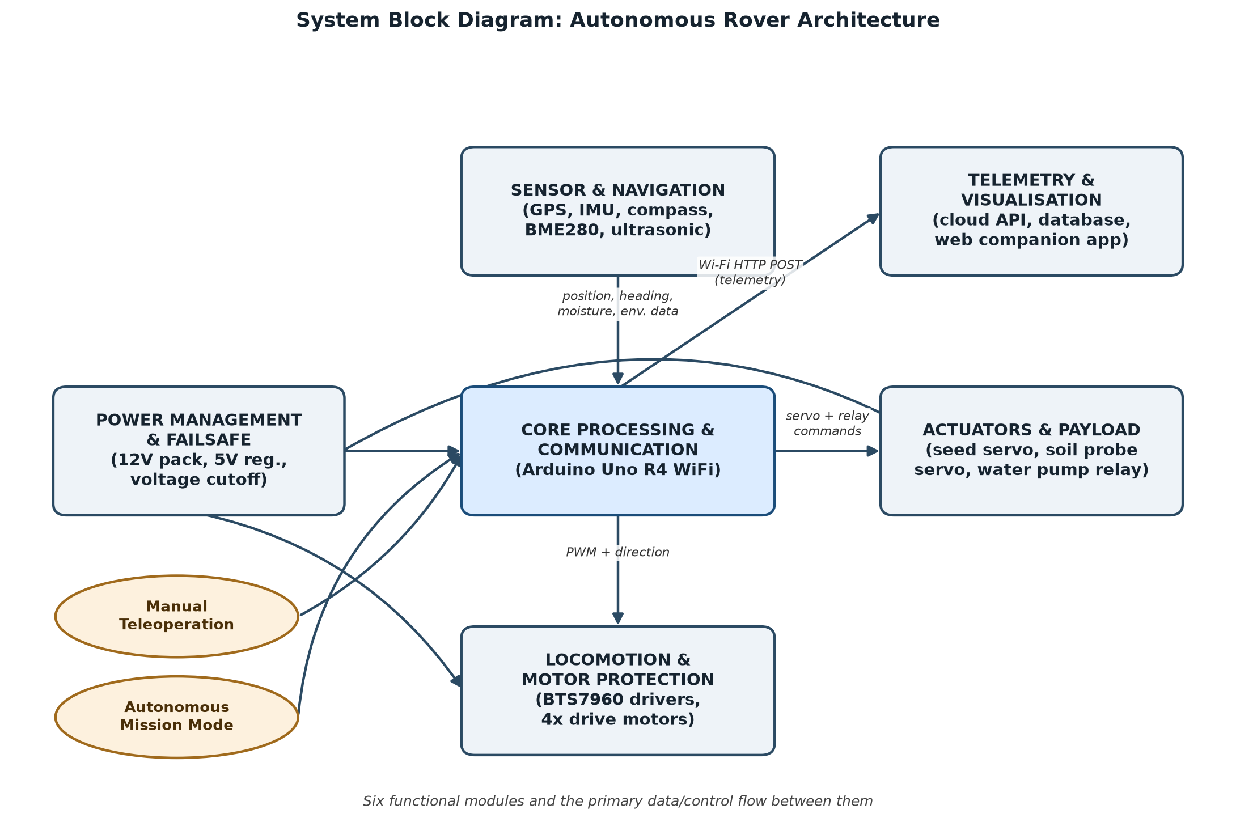
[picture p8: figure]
System block diagram of the six functional modules

Figure 3. 1 System block diagram of the rover architecture

The design went through several rounds of revision before settling on the architecture described in this chapter. Earlier iterations explored a flight-controller-based approach using a Matek F405 board running iNav firmware, with a separate microcontroller handling actuator control and a companion mobile application communicating over the MultiWii Serial Protocol. That approach was abandoned after the project's chosen motor drivers proved incompatible with the PWM signal conventions expected by the alternative ArduRover firmware that was tried first, and after it became clear that a single general-purpose microcontroller could handle the full control loop, sensor fusion, and actuator logic directly, without the added complexity of a flight-controller stack designed primarily for aerial vehicles. The final architecture consolidates control on one Arduino-class microcontroller, which simplifies wiring, debugging, and the bill of materials considerably.
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

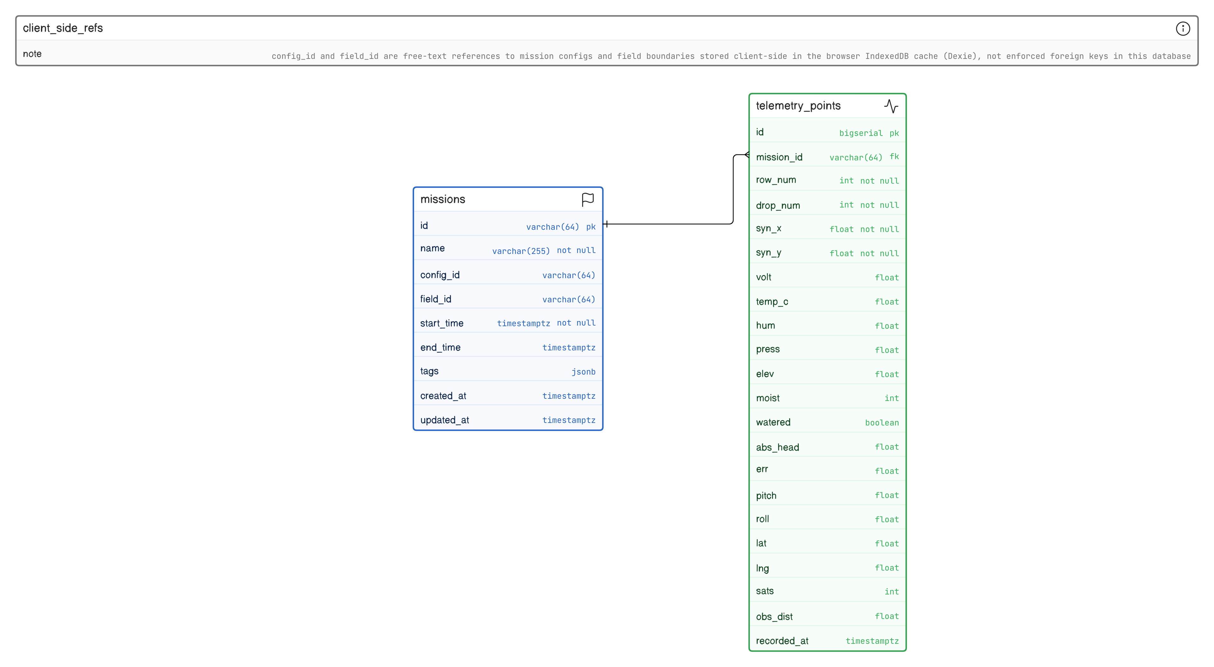
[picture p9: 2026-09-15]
docs/thesis/photos/entity_relationship_diagram.png

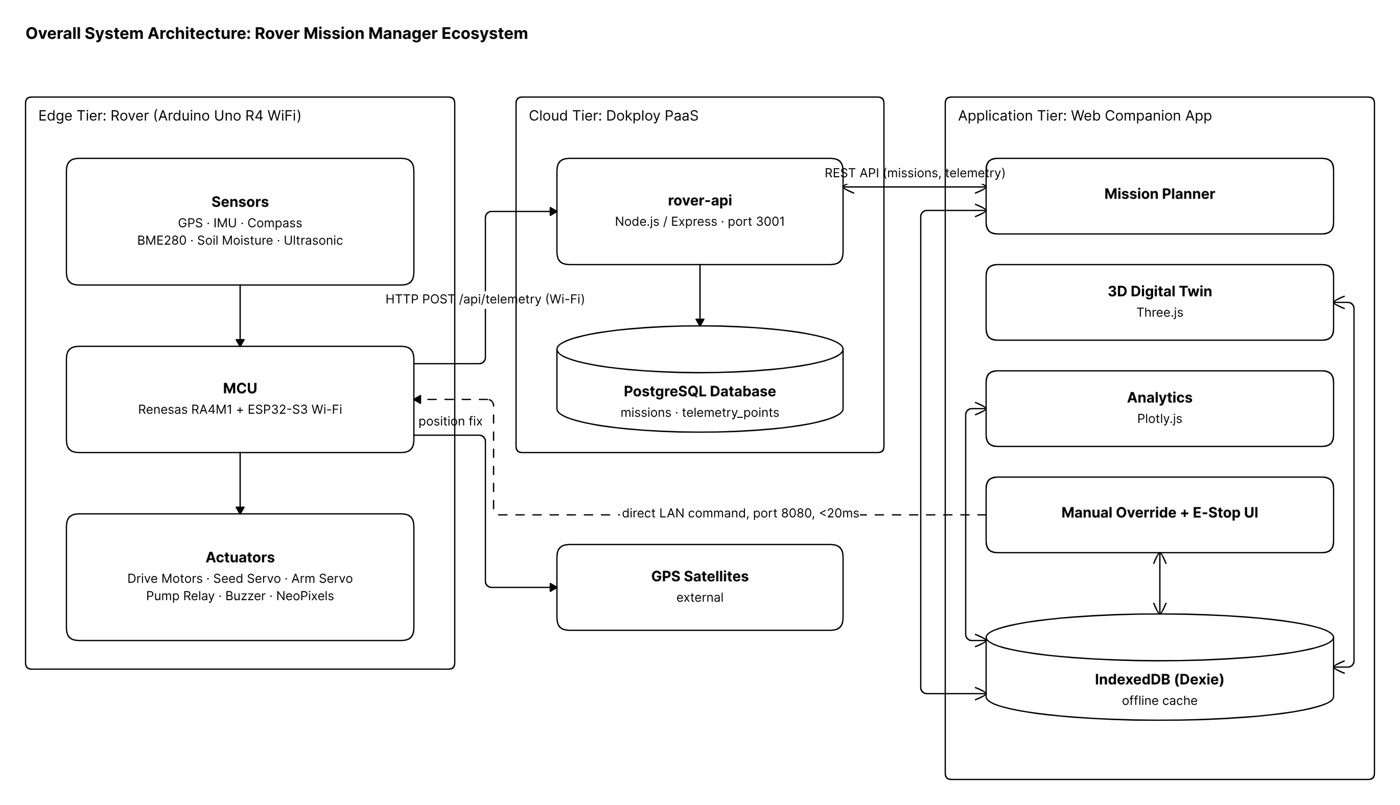
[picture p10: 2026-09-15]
docs/thesis/photos/overall_system_architecture.png

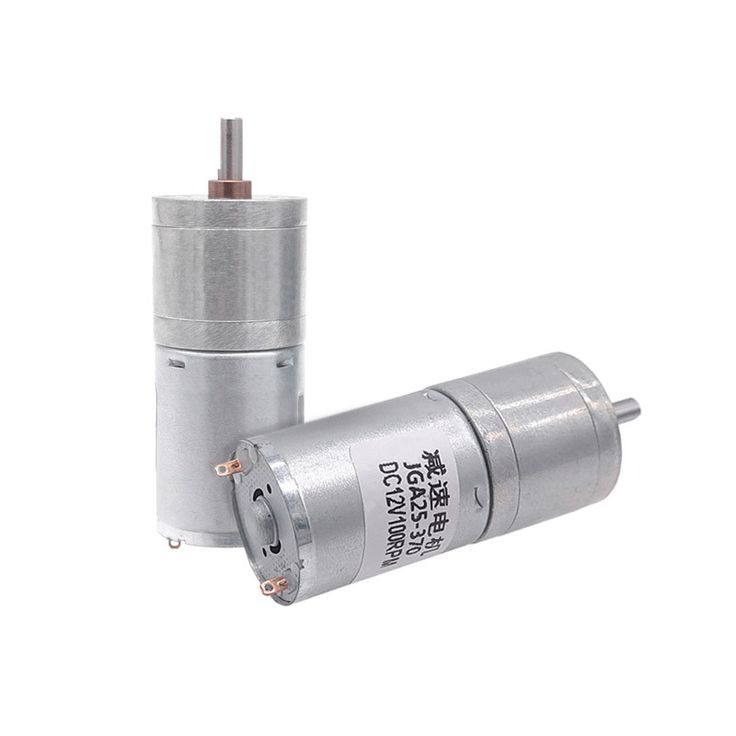
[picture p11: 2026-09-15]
docs/thesis/photos/drive_motor.jpg

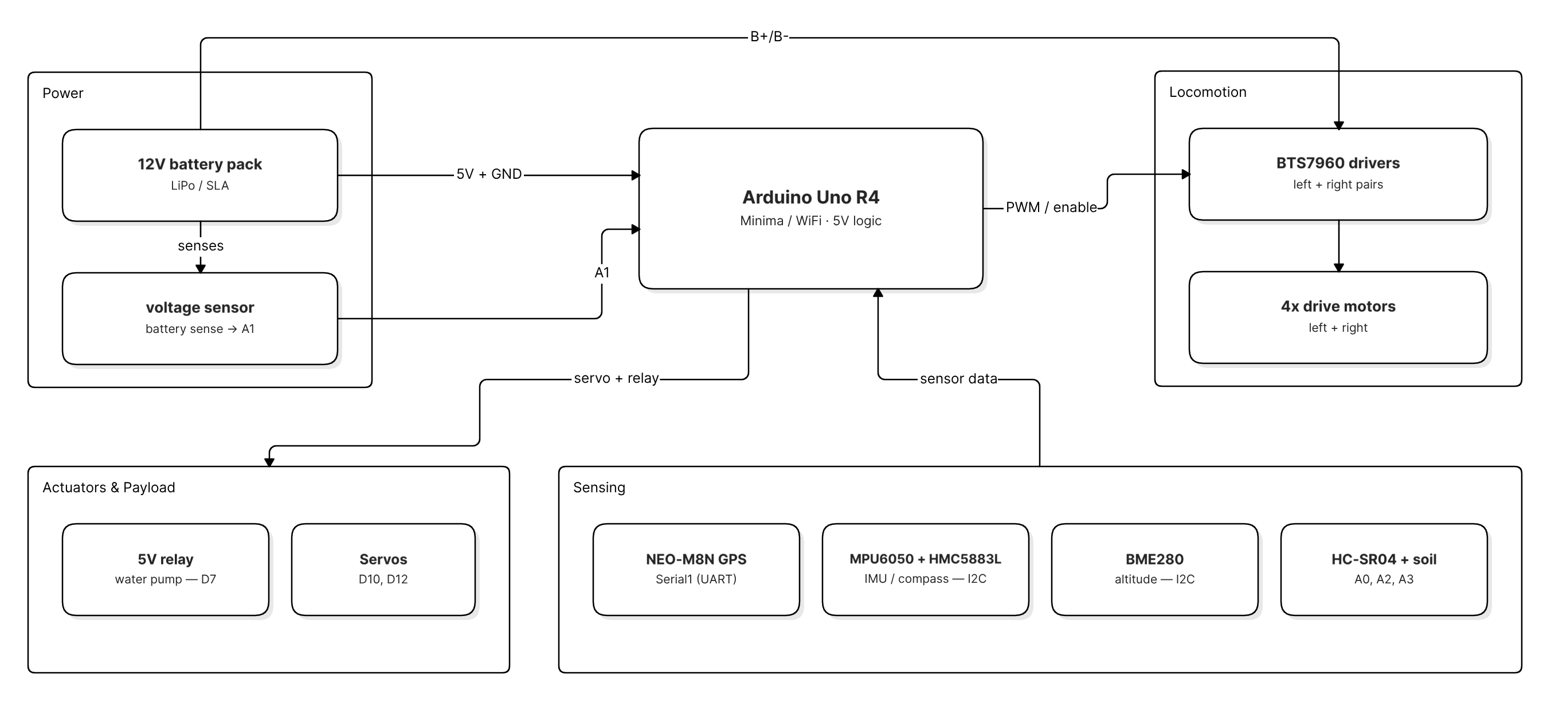
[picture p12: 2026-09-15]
docs/thesis/photos/hardware_architecture_overview.png

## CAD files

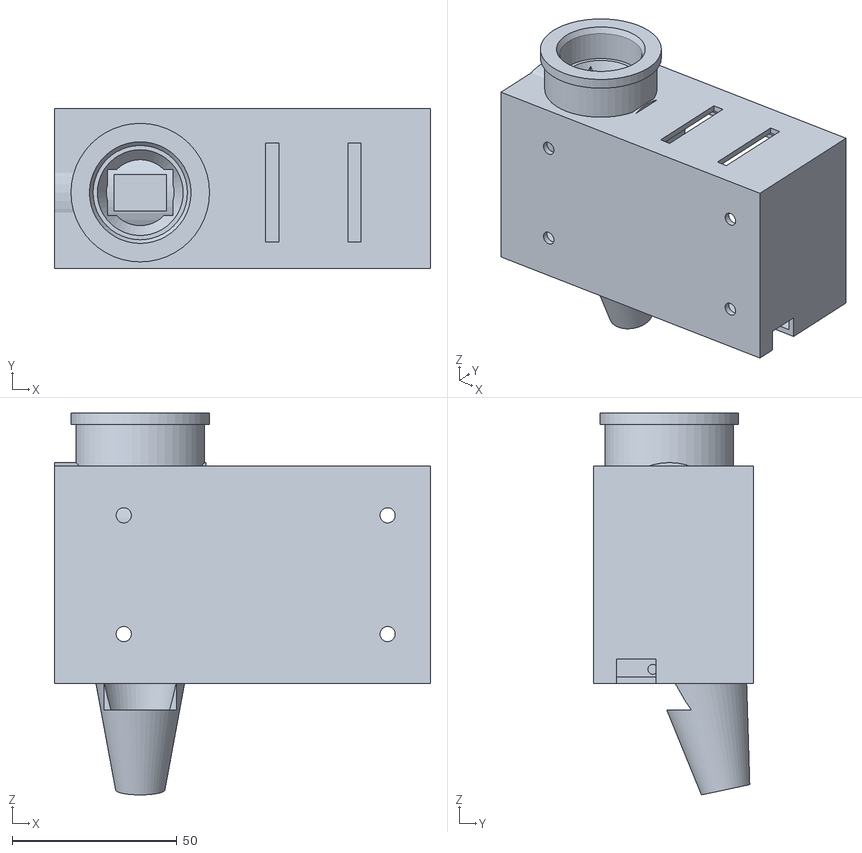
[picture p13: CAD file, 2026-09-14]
models/stl/civ_pod_full_assembly.stl
114.0 x 48.5 x 115.8

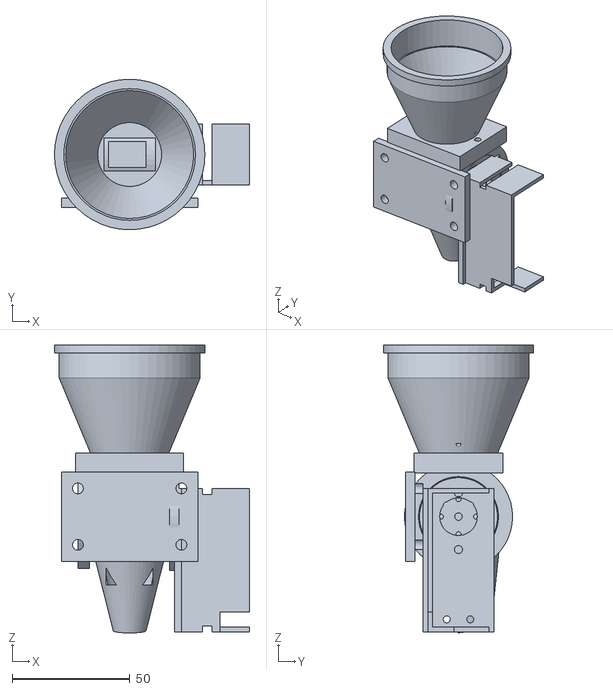
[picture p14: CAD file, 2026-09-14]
models/stl/seed_meter_modular_assembly_2mm.stl
83.0 x 64.0 x 122.5

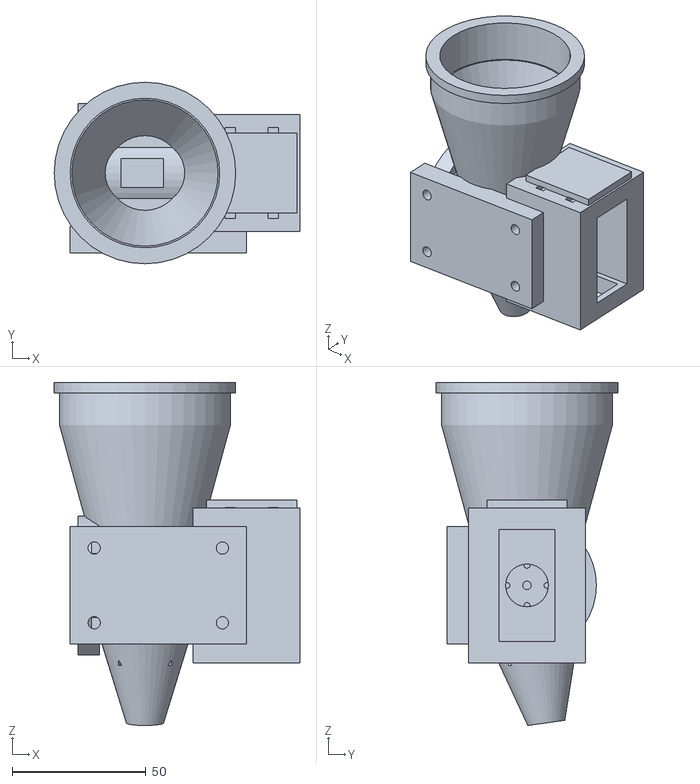
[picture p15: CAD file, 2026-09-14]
models/stl/seed_meter_full_assembly.stl
92.0 x 68.0 x 128.5

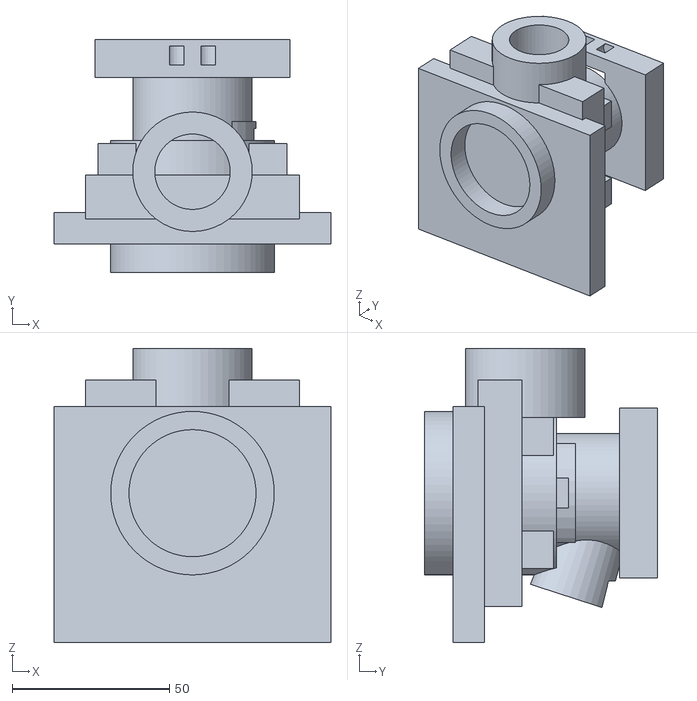
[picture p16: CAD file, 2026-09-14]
models/stl/modular_seeder_full_assembly.stl
88.0 x 74.0 x 93.5

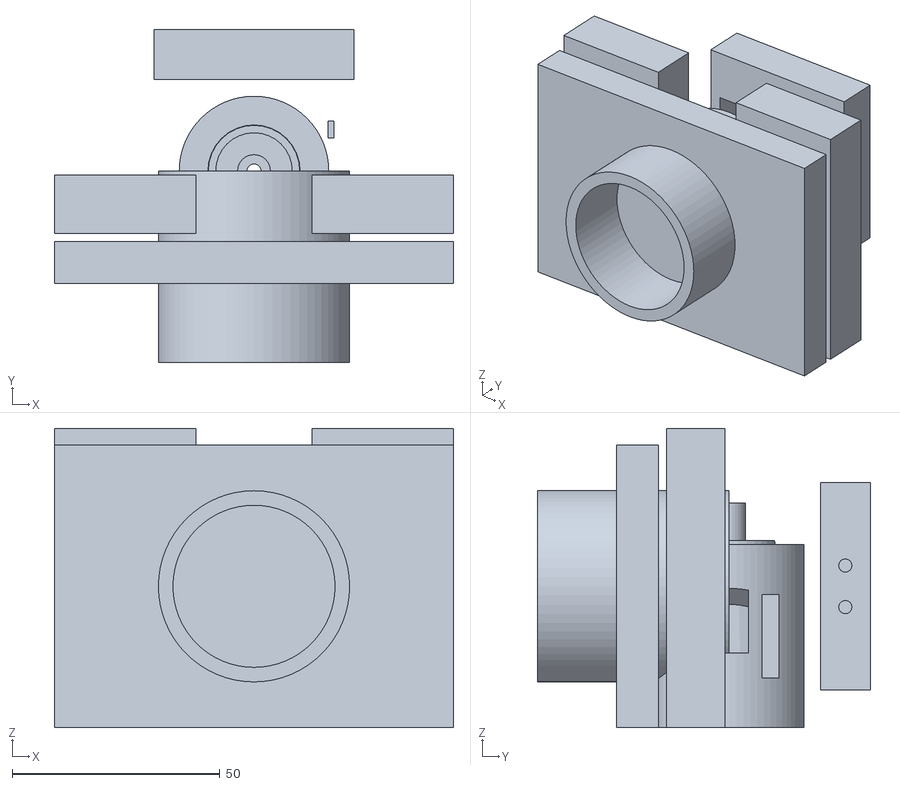
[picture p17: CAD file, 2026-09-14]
models/stl/fail_safe_full_assembly.stl
96.0 x 80.0 x 72.0

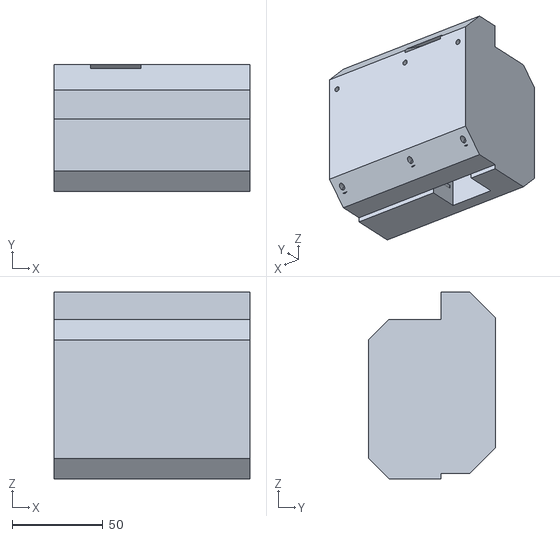
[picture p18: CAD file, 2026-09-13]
models/stl/civ_dispenser_full_assembly.stl
108.0 x 70.0 x 103.0

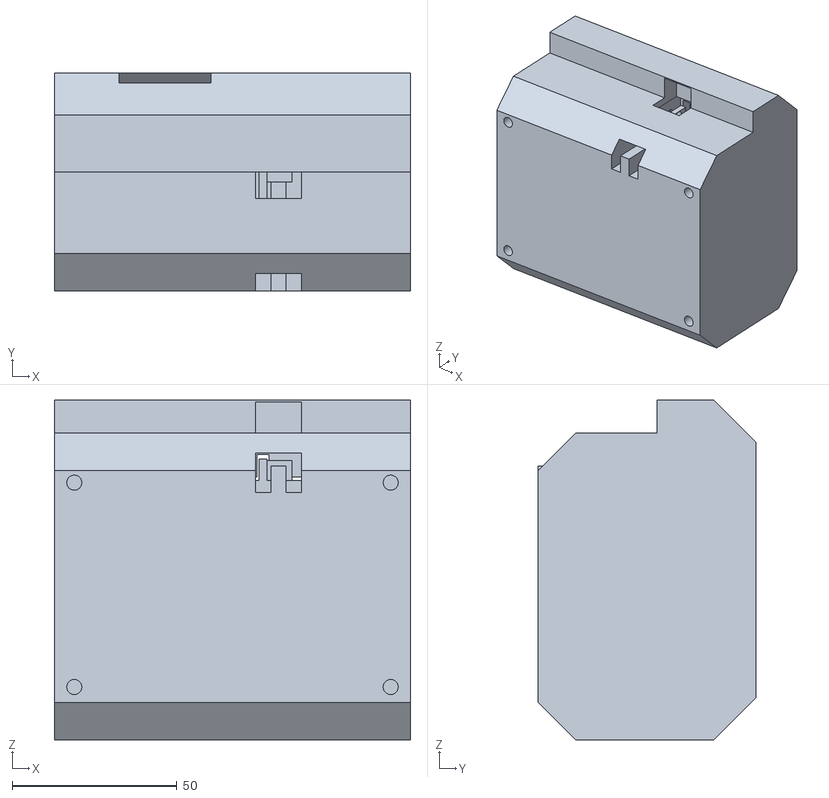
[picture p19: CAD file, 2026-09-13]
models/stl/civ_dispenser_full_assembly_WITH_SERVO.stl
108.0 x 66.0 x 103.0

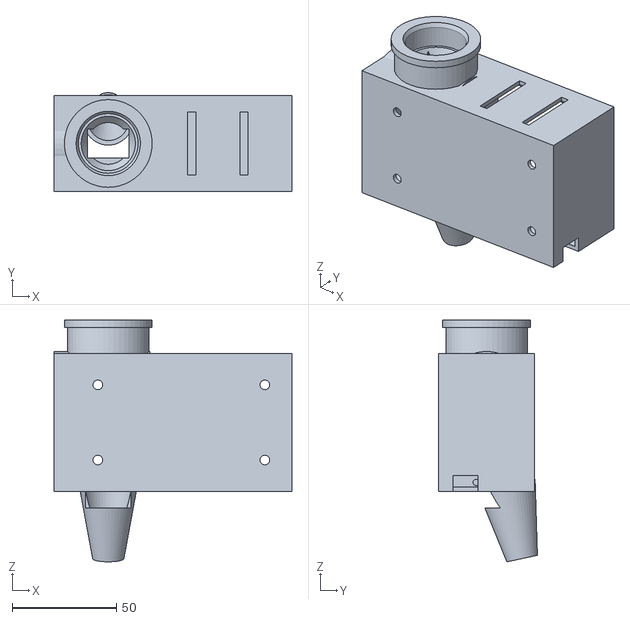
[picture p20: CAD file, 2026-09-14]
models/stl/civ_pod_hollow_chassis.stl
114.0 x 47.4 x 115.8

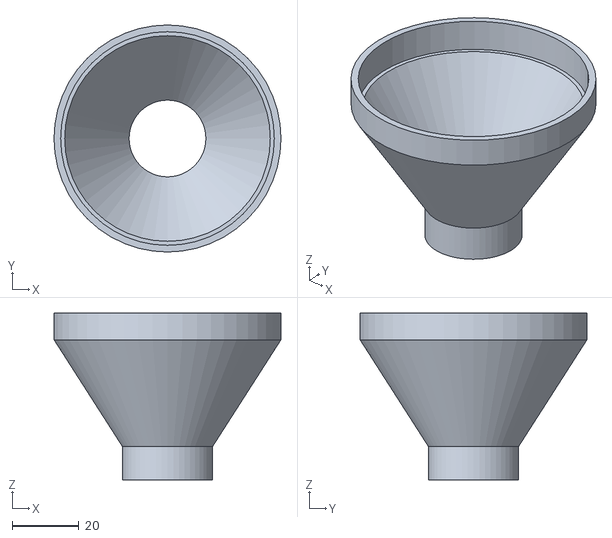
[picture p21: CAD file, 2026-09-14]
models/stl/civ_pod_bottle_funnel_adapter.stl
68.0 x 68.0 x 50.0

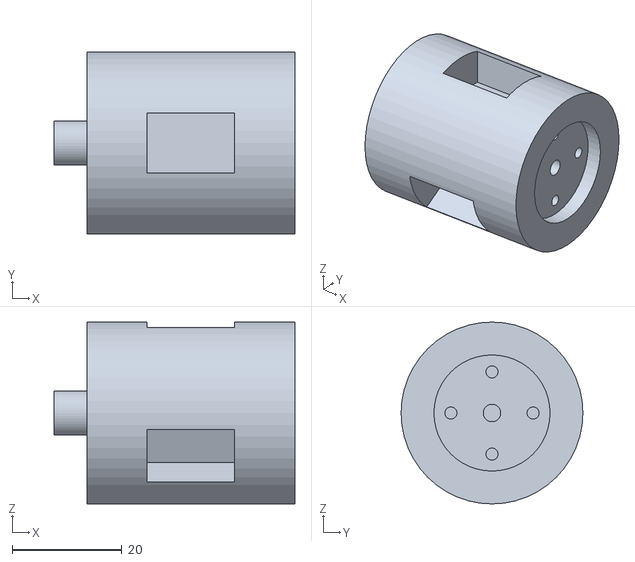
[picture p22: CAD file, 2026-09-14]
models/stl/civ_pod_rotor.stl
44.0 x 33.2 x 33.2

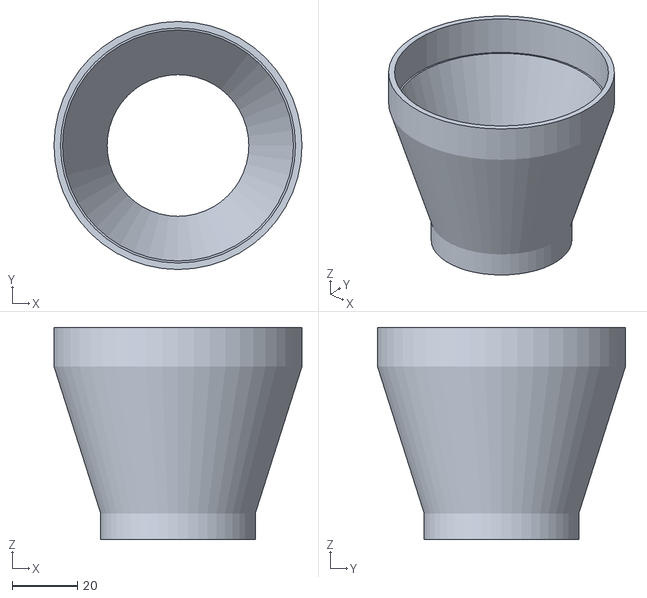
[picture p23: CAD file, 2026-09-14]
models/stl/civ_pod_hopper_funnel.stl
76.0 x 76.0 x 65.0

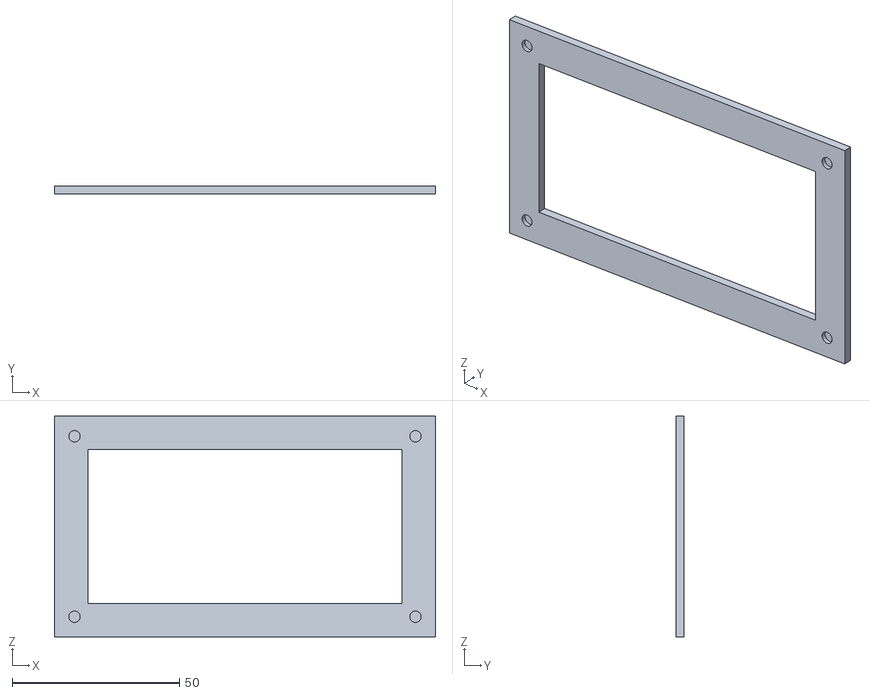
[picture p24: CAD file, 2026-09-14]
models/stl/civ_pod_front_cover.stl
114.0 x 2.50 x 66.0

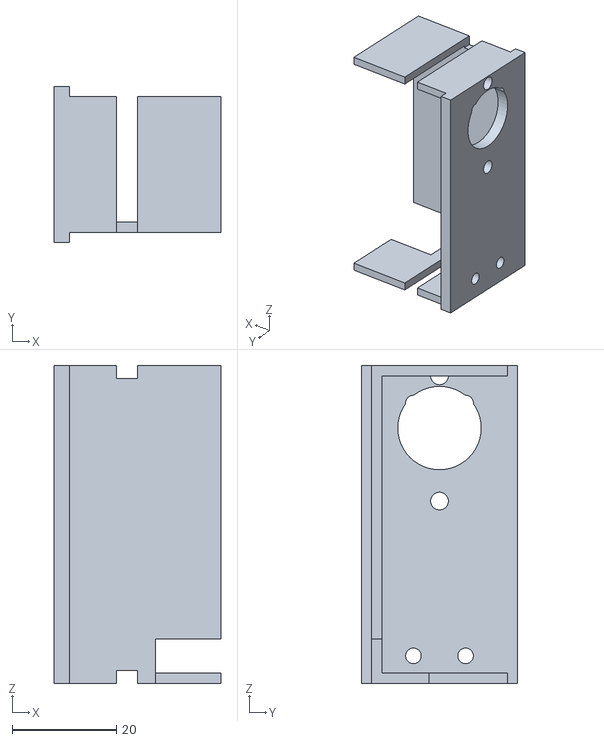
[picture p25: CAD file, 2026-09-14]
models/stl/seed_meter_servo_cradle_2mm.stl
32.0 x 30.0 x 61.0

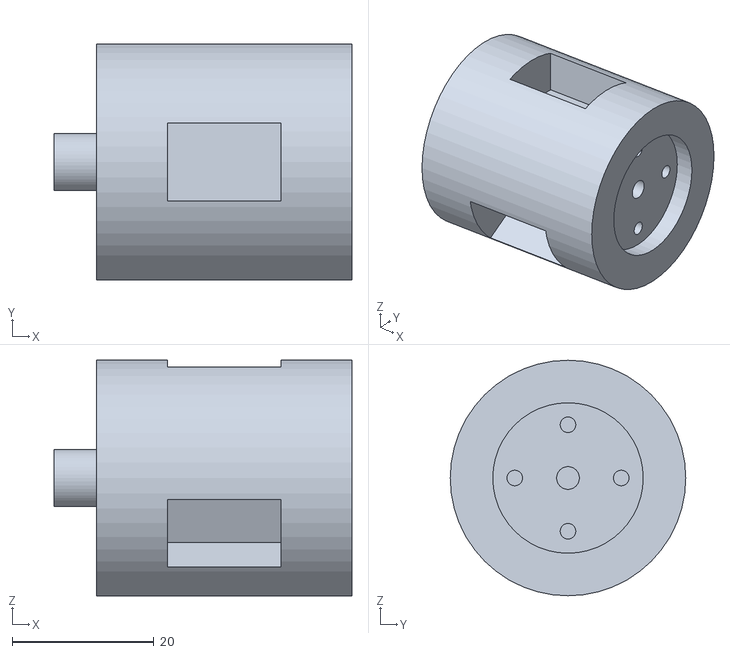
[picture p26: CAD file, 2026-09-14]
models/stl/seed_meter_rotor_2mm.stl
42.0 x 33.2 x 33.2

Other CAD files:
models/stl/seed_meter_funnel_2mm.stl
models/stl/seed_meter_chamber_2mm.stl
models/stl/seed_meter_end_cap_2mm.stl
models/stl/seed_meter_housing.stl
models/stl/civ_dispenser_chassis_base.stl
models/stl/civ_dispenser_front_cover.stl
models/stl/civ_dispenser_open_view_WITH_SERVO.stl
models/stl/civ_dispenser_rotor.stl
models/stl/fail_safe_chassis_mount_housing.stl
models/stl/fail_safe_front_cover_with_bearing.stl
models/stl/fail_safe_rotor.stl
models/stl/mg996r_tower_pro_servo.stl
models/stl/modular_seeder_chassis_base.stl
models/stl/modular_seeder_front_cover.stl
models/stl/modular_seeder_rotor.stl
models/stl/seed_meter_end_cap.stl
models/stl/seed_meter_rotor.stl

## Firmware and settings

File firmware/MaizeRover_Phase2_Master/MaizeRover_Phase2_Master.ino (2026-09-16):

/*
  Maize Rover: Phase 3 Master Firmware (Arduino Uno R4 WiFi)
  Local-First Mission Control, No Internet Required in the Field

  The rover hosts its own WiFi network (Access Point mode) at a fixed address,
  192.168.4.1, instead of joining a farm/phone hotspot. A phone or laptop
  connects directly to that network and talks to the rover over the LAN — there
  is no dependency on mobile data, a nearby router, or a phone's hotspot staying
  awake. Completed missions are logged on the connecting device and can be
  pushed to the cloud afterward, from the app, whenever a connection happens to
  be available; the rover itself never needs one.

  Operational State Machine:
  [BOOT] -> [IDLE: awaiting config/start] -> [AUTO: mission running] <---> [PAUSED]
                                                     |         |
                                                [MANUAL] <-----+
                                                     |
                                                  [ESTOP] (reachable from any state)

  Features:
  - Autonomous boustrophedon driving between planting points: a dual-MPU-6050
    architecture replaces the compass (magnetometers are notoriously noisy this
    close to brushed-DC drive motors). MPU #1 (0x68) provides gyro Z-rate,
    integrated into a local relative-yaw-hold PID (P+I+D against 0 deg drift
    for the current straight segment) and into a running globalYaw estimate
    used only for telemetry/logging (reset to 0 at the start of every mission).
    MPU #2 (0x69) provides Z-axis accelerometer deviation from 1g, used as a
    terrain-roughness/shock metric. Interruptible by E-Stop and pause at every
    control tick, not just between drops. Kp/Ki/Kd/max-correction are
    runtime-tunable via /cmd?action=config so field tuning never needs a reflash.
  - Local mission configuration and lifecycle control over the port-8080 command
    server: config, start_mission, pause_mission, resume_mission, status
  - Status endpoint returns the latest telemetry snapshot and mission progress so a
    companion app on the same local network can poll and log data on-device, with
    no internet connection required
  - Immediate Remote E-Stop override (Zero PWM, pump kill, acoustic alarm)
  - Manual Directional Nudge (Forward, Reverse, Left, Right, Stop) with 600ms deadman timeout
  - Actuator Diagnostic Test Bench (Single Seed Pulse, Water Dose 400ms)
  - Embedded WiFiServer on Port 8080 for low-latency (<20ms) direct commands
  - MPU-6050 Pitch/Roll and MPU-6050 Terrain Roughness (peak Z-axis shock per
    straight-line segment)

  NOTE: The BME280 (temperature/humidity/pressure/elevation) and HMC5883L/
  QMC5883L compass have been removed from this hardware revision. Their
  telemetry/CSV fields are kept in place (always reporting 0) rather than
  deleted, so the companion app's status JSON contract doesn't break.
  The ultrasonic obstacle sensor and the soil-probe arm servo have also been
  physically removed from this hardware revision; unlike the BME280/compass
  fields, their telemetry (obsDist) and command (test_arm) have been deleted
  outright rather than zeroed, since a fake "0cm to obstacle" reading would be
  actively misleading rather than just unavailable.
*/

#include <Wire.h>
#include <Servo.h>
#include <math.h>
#include <TinyGPSPlus.h>
#include <Adafruit_NeoPixel.h>
#include <WiFiS3.h>

// =========================================================================
// OPERATIONAL STATE MACHINE DEFINITIONS
// =========================================================================
enum RoverMode {
  MODE_IDLE,      // Awaiting mission configuration and start command from the app
  MODE_AUTO,      // Mission running: autonomous furrow traversal & planting
  MODE_PAUSED,    // Mission interrupted mid-run; holds position, resumable
  MODE_MANUAL,    // Operator teleop & actuator diagnostics
  MODE_ESTOP      // Emergency stop: all power cut, pump off, alarm
};

RoverMode currentMode = MODE_IDLE;

// =========================================================================
// NETWORK CONFIGURATION (Access Point mode)
// =========================================================================
// The rover hosts its own network rather than joining one, so the connecting
// phone/laptop always finds it at the same address (192.168.4.1, assigned by
// the WiFiS3 library's default AP configuration) with no router or mobile
// hotspot involved. Change the password below before field deployment;
// WPA2 requires 8-63 characters.
const char* AP_SSID       = "MaizeRover-Field01";
const char* AP_PASSWORD   = "PlantMaize1";

// Embedded Command Server for Local Subnet Teleop & E-Stop
WiFiServer cmdServer(8080);

// =========================================================================
// I2C ADDRESSES
// =========================================================================
#define MPU_STEERING      0x68  // Gyro Z-rate: closed-loop straight-line hold + turn tracking
#define MPU_ROUGHNESS     0x69  // Z-axis accelerometer: terrain roughness / shock sensing

// =========================================================================
// PIN DEFINITIONS (No SD Card Contention)
// =========================================================================
#define MOISTURE_PIN      A0
#define VOLTAGE_PIN       A1

#define MOTOR_LEFT_RPWM   3
#define MOTOR_LEFT_EN     4   // Dedicated to Left Motor Enable
#define MOTOR_LEFT_LPWM   5
#define MOTOR_RIGHT_RPWM  6
#define PUMP_RELAY_PIN    7   // Active LOW relay for water pump
#define MOTOR_RIGHT_EN    8   // Dedicated to Right Motor Enable
#define MOTOR_RIGHT_LPWM  9
#define SEED_SERVO_PIN    10  // Dispenser hopper gate
#define BUZZER_PIN        11  // Audio alert / obstacle buzzer
#define RGB_PIN           13  // WS2812B Status Indicator

// =========================================================================
// FIELD GEOMETRY & TUNING (runtime-configurable via /cmd?action=config...)
// =========================================================================
#define NUM_LEDS           8
int         BASE_SPEED     = 100;
int         TURN_SPEED     = 100;
const bool  LEFT_INVERT    = false;
const bool  RIGHT_INVERT   = true;  // Opposing motor mounted on right chassis
float       DROP_SPACING_M = 0.25;
float       ROW_SPACING_M  = 0.75;
int         DROPS_PER_ROW  = 20;
int         TOTAL_ROWS     = 10;
int         MOIST_THRESHOLD= 450;
const unsigned long DRIVE_DEADMAN_TIMEOUT = 600; // Auto-stop motors after 600ms of silence

// Closed-loop straight-line driving: local relative-yaw hold (P) + accumulated
// error (I) + yaw-rate derivative (D) against the MPU_STEERING gyro, runtime-
// configurable via /cmd?action=config so gains can be tuned in the field
// without reflashing. Bench-tuned for the low BASE_SPEED above.
float       Kp             = 3.5;
float       Ki             = 0.05;
float       Kd             = 1.0;
int         MAX_CORRECTION = 30;      // Dropped from 55 to prevent low-speed stalling
float       EARLY_TURN_CUTOFF = 2.0;  // Stop actively driving this many degrees early and coast the rest -- prevents low-speed turn overshoot

// Time-based distance estimate (no wheel encoders): milliseconds of
// BASE_SPEED driving to cover one meter, calibrated empirically on the bench.
// Re-measure if BASE_SPEED, wheels, gearing, or battery voltage change --
// these two are independently tuned because the row-gap crossing includes
// the U-turn's own settling and isn't simply proportional to the per-drop one.
const float MS_PER_METER_DROP    = 8000.0;
const float MS_PER_METER_ROW_GAP = 4000.0;
const float PIVOT_ANGLE_DEG      = 90.0; // Row-to-row U-turn is two of these

// Mission lifecycle state
bool missionActive     = false; // true once start_mission has been called
bool missionComplete   = false; // true once TOTAL_ROWS has been fully covered

// Objects
TinyGPSPlus gps;
Adafruit_NeoPixel strip(NUM_LEDS, RGB_PIN, NEO_GRB + NEO_KHZ800);
Servo seedServo;

// State Variables
int currentRow = 1;
int currentDrop = 0;
unsigned long lastDropTime = 0;
unsigned long lastDriveCommandTime = 0;

// Closed-loop navigation state
float gyroZOffset   = 0.0;  // Measured at boot; subtract from raw gyro Z to get real rate
float globalYaw     = 0.0;  // Accumulated heading since boot -- acts as a drift-prone "digital compass" now that the magnetometer (noisy near the drive motors) has been removed. Telemetry/logging only; steering itself holds local relative yaw, not this.
float maxRoughness  = 0.0;  // Peak Z-axis shock measured during the current straight-line segment
float lastPIDError  = 0.0;  // Most recent local-yaw error from the last driveStraightPID poll, exposed as telemetry "err"

// Latest telemetry snapshot, exposed via /cmd?action=status so a companion app on
// the local network can poll it and log each drop on-device. telemetrySeq
// increments once per drop so the app can tell whether a poll returned a new
// reading or the same one as last time. tempC/hum/press/elev are always 0
// now that the BME280 has been removed from this hardware revision -- kept
// in the JSON shape rather than deleted so the app doesn't need to change.
unsigned long telemetrySeq = 0;
float lastSynX = 0, lastSynY = 0, lastVolt = 0, lastTempC = 0, lastHum = 0, lastPress = 0, lastElev = 0;
int   lastMoist = 0;
bool  lastWatered = false;
float lastAbsHead = 0, lastErr = 0, lastPitch = 0, lastRoll = 0, lastLat = 0, lastLng = 0;
float lastRoughness = 0;
int   lastSats = 0;

// =========================================================================
// SETUP
// =========================================================================
void setup() {
  Serial.begin(115200);
  Serial1.begin(9600); // GPS
  Wire.begin();

  // Pin Configurations
  pinMode(MOTOR_LEFT_EN, OUTPUT);
  pinMode(MOTOR_RIGHT_EN, OUTPUT);
  digitalWrite(MOTOR_LEFT_EN, HIGH);
  digitalWrite(MOTOR_RIGHT_EN, HIGH);

  pinMode(MOTOR_LEFT_RPWM, OUTPUT);
  pinMode(MOTOR_LEFT_LPWM, OUTPUT);
  pinMode(MOTOR_RIGHT_RPWM, OUTPUT);
  pinMode(MOTOR_RIGHT_LPWM, OUTPUT);

  pinMode(PUMP_RELAY_PIN, OUTPUT);
  digitalWrite(PUMP_RELAY_PIN, HIGH); // Turn off pump (Active LOW)

  pinMode(BUZZER_PIN, OUTPUT);

  // Servo
  seedServo.attach(SEED_SERVO_PIN);
  seedServo.write(0);  // Gate closed

  // NeoPixels
  strip.begin();
  setRGBColor(strip.Color(255, 120, 0)); // Amber: Booting
  strip.show();

  // Wake up both MPU-6050s. 0x68 drives closed-loop steering (gyro Z) and
  // needs the low-pass filter + full-scale range configured for clean rate
  // readings; 0x69 only ever reads the raw Z-axis accelerometer for shock
  // sensing, so its power-on defaults are fine once it's out of sleep.
  Wire.beginTransmission(MPU_STEERING);
  Wire.write(0x6B);
  Wire.write(0);
  Wire.endTransmission(true);
  Wire.beginTransmission(MPU_STEERING); Wire.write(0x1A); Wire.write(0x03); Wire.endTransmission(); // 44Hz digital low-pass filter
  Wire.beginTransmission(MPU_STEERING); Wire.write(0x1B); Wire.write(0x00); Wire.endTransmission(); // +/-250 deg/s full scale

  Wire.beginTransmission(MPU_ROUGHNESS);
  Wire.write(0x6B);
  Wire.write(0);
  Wire.endTransmission(true);

  // Gyro Z-axis calibration: average the drift while stationary so
  // readGyroZRate() can report true angular velocity, not sensor bias.
  Serial.println(F("[NAV] Calibrating gyro, keep the rover still..."));
  float gyroSum = 0.0;
  for (int i = 0; i < 200; i++) {
    gyroSum += readRawGyroZ();
    delay(5);
  }
  gyroZOffset = gyroSum / 200.0;
  Serial.println(F("[NAV] Gyro calibrated."));

  // Host the local Access Point & Launch Command Server
  setupAccessPoint();
  cmdServer.begin();

  // Acoustic Ready Chime
  tone(BUZZER_PIN, 1200, 120);
  delay(140);
  tone(BUZZER_PIN, 1800, 180);
  setRGBColor(strip.Color(0, 120, 255)); // Blue: idle, awaiting mission config/start from the app
  strip.show();

  Serial.println("Row,Drop,SynX,SynY,Volt,TempC,Hum,Press,Elev,Moist,Watered,AbsHead,Err,Pitch,Roll,Lat,Lng,Sats,Roughness");
}

// =========================================================================
// MAIN LOOP
// =========================================================================
void loop() {
  // 1. Process GPS stream
  while (Serial1.available() > 0) {
    gps.encode(Serial1.read());
  }

  // 2. Process Remote Teleop & E-Stop HTTP Commands
  handleIncomingCommands();

  // 3. State Machine Branching
  switch (currentMode) {
    case MODE_ESTOP:
      // Safety Lockdown: 0% PWM, forced pump cut
      stopMotors();
      digitalWrite(PUMP_RELAY_PIN, HIGH);
      // Warning strobe
      if ((millis() / 250) % 2 == 0) {
        setRGBColor(strip.Color(255, 0, 0));
        tone(BUZZER_PIN, 1000, 50);
      } else {
        setRGBColor(strip.Color(0, 0, 0));
      }
      break;

    case MODE_MANUAL:
      // Manual Override: Deadman timeout safety
      if (millis() - lastDriveCommandTime > DRIVE_DEADMAN_TIMEOUT) {
        stopMotors();
      }
      setRGBColor(strip.Color(255, 140, 0)); // Solid Amber
      break;

    case MODE_IDLE:
      // Awaiting a config + start_mission command from the app. Motors stay off.
      stopMotors();
      setRGBColor(strip.Color(0, 120, 255)); // Blue: idle
      break;

    case MODE_PAUSED:
      // Mission interrupted mid-run. Position (currentRow/currentDrop) is held
      // so resume_mission can continue from exactly where it left off.
      stopMotors();
      setRGBColor(strip.Color(255, 200, 0)); // Amber-yellow: paused
      break;

    case MODE_AUTO:
    default: {
      setRGBColor(strip.Color(0, 255, 0)); // Solid Green

      // Mission-complete check: currentRow only advances past TOTAL_ROWS once
      // the last row's final drop has been executed.
      if (currentRow > TOTAL_ROWS) {
        stopMotors();
        missionActive = false;
        missionComplete = true;
        currentMode = MODE_IDLE;
        tone(BUZZER_PIN, 1500, 150);
        delay(160);
        tone(BUZZER_PIN, 2000, 200);
        Serial.println("[MISSION] Complete.");
        return;
      }

      // Autonomous Furrow Cycle (every 2.5s)
      if (millis() - lastDropTime >= 2500) {
        lastDropTime = millis();
        executePlantingDrop();
      }
      break;
    }
  }
}

// =========================================================================
// COMMAND SERVER & TELEOP HANDLER (PORT 8080)
// =========================================================================

// Extracts the value of a query-string key (e.g. "rows" from "...&rows=10&...").
// Returns "" if the key isn't present in the request.
String getParam(String req, String key) {
  String pattern = key + "=";
  int idx = req.indexOf(pattern);
  if (idx == -1) return "";
  idx += pattern.length();
  int end = idx;
  while (end < (int)req.length() && req[end] != '&' && req[end] != ' ') end++;
  return req.substring(idx, end);
}
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

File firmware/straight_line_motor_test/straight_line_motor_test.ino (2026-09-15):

/*
 * =========================================================================
 * Straight Line Motor Diagnostic Test (Dual BTS7960 / IBT-2 / L298N)
 * Target: Arduino Uno R4 WiFi / Uno R3
 * 
 * FIXED HARDWARE WIRING:
 *  - Left Driver:   RPWM = 3, LPWM = 5, EN = 4
 *  - Right Driver:  RPWM = 6, LPWM = 9, EN = 8
 * 
 * Test Routine:
 *  - 5-cycle Straight Line Test:
 *      1. Drive STRAIGHT FORWARD for 2.0 seconds
 *      2. Full STOP for 1.5 seconds
 *      3. Repeat exactly 5 times
 *  - Complete safe shutdown when finished.
 * 
 * Open Serial Monitor at 115200 baud to follow along.
 * =========================================================================
 */

// =========================================================================
// 1. FIXED PIN DEFINITIONS (DO NOT CHANGE - MATCHED TO YOUR HARDWARE)
// =========================================================================
const uint8_t L_RPWM = 3;
const uint8_t L_LPWM = 5;
const uint8_t L_R_EN = 4;
const uint8_t L_L_EN = 4;

const uint8_t R_RPWM = 6;
const uint8_t R_LPWM = 9;
const uint8_t R_R_EN = 8;
const uint8_t R_L_EN = 8;

// =========================================================================
// 2. MOTOR PARAMETERS & INVERSION
// =========================================================================
// If either side spins in reverse during forward test, toggle its invert flag
const bool LEFT_INVERT  = false;
const bool RIGHT_INVERT = true;  // Opposing motor mounted on right chassis

// Speed: 0 (stopped) to 255 (max). 200 provides strong torque.
const int DRIVE_SPEED = 200;

const int TOTAL_CYCLES       = 5;
const unsigned long RUN_MS   = 2000; // 2.0 seconds forward
const unsigned long PAUSE_MS = 1500; // 1.5 seconds stop

// =========================================================================
// 3. LOW-LEVEL MOTOR DRIVER FUNCTIONS
// =========================================================================

void enableDrivers(bool enable) {
  uint8_t state = enable ? HIGH : LOW;
  digitalWrite(L_R_EN, state);
  digitalWrite(L_L_EN, state);
  digitalWrite(R_R_EN, state);
  digitalWrite(R_L_EN, state);
}

void driveSide(uint8_t rpwmPin, uint8_t lpwmPin, int speed, bool invert) {
  if (invert) speed = -speed;
  speed = constrain(speed, -255, 255);

  if (speed > 0) {
    analogWrite(lpwmPin, 0);
    analogWrite(rpwmPin, speed);
  } else if (speed < 0) {
    analogWrite(rpwmPin, 0);
    analogWrite(lpwmPin, -speed);
  } else {
    analogWrite(rpwmPin, 0);
    analogWrite(lpwmPin, 0);
  }
}

void driveStraight(int speed) {
  driveSide(L_RPWM, L_LPWM, speed, LEFT_INVERT);
  driveSide(R_RPWM, R_LPWM, speed, RIGHT_INVERT);
}

void stopMotors() {
  driveSide(L_RPWM, L_LPWM, 0, false);
  driveSide(R_RPWM, R_LPWM, 0, false);
}

// =========================================================================
// 4. SETUP & TEST EXECUTION
// =========================================================================

void setup() {
  Serial.begin(115200);
  delay(1200);

  Serial.println(F("\n============================================="));
  Serial.println(F("  STRAIGHT LINE MOTOR TEST (5 CYCLES)"));
  Serial.println(F("  FIXED PINOUT: Left=3,5 (EN=4) | Right=6,9 (EN=8)"));
  Serial.println(F("============================================="));
  Serial.print(F("Parameters: Speed=")); Serial.print(DRIVE_SPEED);
  Serial.print(F(" | Run=")); Serial.print(RUN_MS / 1000.0, 1);
  Serial.print(F("s | Pause=")); Serial.print(PAUSE_MS / 1000.0, 1);
  Serial.print(F("s | Cycles=")); Serial.println(TOTAL_CYCLES);
  Serial.println(F("---------------------------------------------"));

  // 1. Initialize Driver Pins as Outputs
  pinMode(L_RPWM, OUTPUT);
  pinMode(L_LPWM, OUTPUT);
  pinMode(L_R_EN, OUTPUT);
  pinMode(L_L_EN, OUTPUT);

  pinMode(R_RPWM, OUTPUT);
  pinMode(R_LPWM, OUTPUT);
  pinMode(R_R_EN, OUTPUT);
  pinMode(R_L_EN, OUTPUT);

  pinMode(LED_BUILTIN, OUTPUT);

  // 2. Start with motors completely off
  stopMotors();

  // 3. Drive Enable Pins HIGH (Powers the H-Bridge output stage)
  enableDrivers(true);
  Serial.println(F("[PINS] Left Enable (Pin 4) & Right Enable (Pin 8) = HIGH"));

  // 4. 3-second safety countdown
  Serial.println(F("[SAFETY] Starting test in 3 seconds..."));
  for (int i = 3; i > 0; i--) {
    Serial.print(F("  Countdown: "));
    Serial.println(i);
    digitalWrite(LED_BUILTIN, HIGH);
    delay(200);
    digitalWrite(LED_BUILTIN, LOW);
    delay(800);
  }

  // 5. Execute 5 Cycles: 2s Forward -> 1.5s Stop
  for (int cycle = 1; cycle <= TOTAL_CYCLES; cycle++) {
    Serial.print(F("\n>>> [CYCLE "));
    Serial.print(cycle);
    Serial.print(F("/"));
    Serial.print(TOTAL_CYCLES);
    Serial.println(F("] DRIVING FORWARD (2 seconds)..."));

    digitalWrite(LED_BUILTIN, HIGH);
    driveStraight(DRIVE_SPEED);
    delay(RUN_MS);

    Serial.print(F(">>> [CYCLE "));
    Serial.print(cycle);
    Serial.print(F("/"));
    Serial.print(TOTAL_CYCLES);
    Serial.println(F("] STOP (1.5 seconds)..."));

    stopMotors();
    digitalWrite(LED_BUILTIN, LOW);
    delay(PAUSE_MS);
  }

  // 6. Test Finished: Safely cut enable pins and motor PWM
  enableDrivers(false);
  stopMotors();

  Serial.println(F("\n============================================="));
  Serial.println(F("  SUCCESS: All 5 cycles completed!"));
  Serial.println(F("  Motors safely disabled and shut down."));
  Serial.println(F("=============================================\n"));
}

void loop() {
  // Idle: Keep motors completely off
  digitalWrite(LED_BUILTIN, LOW);
  delay(1000);
}

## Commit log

2026-09-13 Add project report with system diagrams and companion app screenshots
    Fills in three of five figure placeholders in the thesis: a system
    block diagram and circuit wiring diagram generated from the verified
    firmware pinout, and four new figures showing the actual companion web
    app (Mission Planner, manual override/E-Stop, 3D digital twin, Plotly
    elevation surface) captured from a running build. Also corrects the
    software architecture section, which described the Mission Planner as
    not yet implemented even though it already exists in this repo.
    Three placeholders are left as-is (assembled chassis photo, simulated
    path plot, field trial photo) since no real photos or trial data exist
    yet; see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
2026-09-13 feat(cad): add 3D-printable watertight STL files for modular rotary drum seed dispenser
    [civ_dispenser_chassis_base.stl, civ_dispenser_front_cover.stl, civ_dispenser_full_assembly.stl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]
2026-09-14 feat(cad): add fail-safe dual-bearing rotary seeder STLs with anti-shear silicone wiper and ramped pocket
    [fail_safe_chassis_mount_housing.stl, fail_safe_front_cover_with_bearing.stl, fail_safe_full_assembly.stl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]
2026-09-14 feat(cad): add modular seed dispenser pod STLs with visible MG996R 4-bolt motor mount and chassis slots
    [modular_seeder_chassis_base.stl, modular_seeder_front_cover.stl, modular_seeder_full_assembly.stl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]
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2026-09-14 feat(cad): add photo-matched precision rotary seed dispenser STLs (housing, rotor, end cap, assembly)
    [seed_meter_end_cap.stl, seed_meter_full_assembly.stl, seed_meter_housing.stl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]
2026-09-14 feat(cad): add 2mm modular zero-support rotary seed dispenser STLs
    [seed_meter_chamber_2mm.stl, seed_meter_end_cap_2mm.stl, seed_meter_funnel_2mm.stl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]
2026-09-14 fix(cad): open drop-in servo saddle with direct screwdriver line-of-sight
    [seed_meter_modular_assembly_2mm.stl, seed_meter_servo_cradle_2mm.stl]
2026-09-14 fix(cad): calibrate MG996R servo shaft 10.15mm off-center offset and ear pitch
    [seed_meter_modular_assembly_2mm.stl, seed_meter_servo_cradle_2mm.stl]
2026-09-14 feat(cad): add sleek 2mm hollow boxy CIV-style seeder pod STLs matching rover seeding spec
    [civ_pod_front_cover.stl, civ_pod_full_assembly.stl, civ_pod_hollow_chassis.stl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]
2026-09-14 feat(cad): add 28mm bottle thread collar and built-in servo cradle to boxy hollow pod
    [civ_pod_bottle_funnel_adapter.stl, civ_pod_full_assembly.stl, civ_pod_hollow_chassis.stl]
2026-09-14 Add photographic reference table for electronics components
    Adds a new Table 3.4 with a photo, name, and short function note for
    15 real components, sourced from the actual parts photographed for
    this build. Two of those (a B25 voltage sensor module and a master
    power rocker switch) were not previously itemised, so they are added
    to the Table 3.2 Bill of Materials as well. Also corrects the drive
    motor part number to JGA25-370 to match the part actually
    photographed, in place of the previously listed 25GA-370.
    Still pending real photos: the 12V battery pack and the assembled
    chassis (Figure 3.2 remains a placeholder).
2026-09-14 Add software architecture diagram as new Figure 3.4
    Inserts the Eraser-generated dual-mode software architecture diagram
    at the start of Section 3.8, showing the ROS 2 development/simulation
    tier, the standalone Arduino firmware tier, and the cloud/companion
    app tier. Since this figure lands before the four companion-app
    screenshots added earlier in this section, those are renumbered from
    Figures 3.4-3.7 to 3.5-3.8 in the two places that reference them by
    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
2026-09-15 Add use case diagram and ERD as Figures 3.10 and 3.11
    Adds the Eraser-generated use case diagram (operator and rover
    actors against the system's main use cases) and the entity
    relationship diagram for the PostgreSQL telemetry database
    (missions and telemetry_points, verified against server/db.js),
    both placed at the end of Chapter Three alongside the other
    supplementary diagrams.
2026-09-15 Add hardware architecture overview as Figure 3.12
    Adds the Eraser-generated hardware-grouped view (power, locomotion,
    sensing, actuators around the Arduino Uno R4) as its own new figure,
    distinct from the six-module system block diagram in Figure 3.1 and
    the pin-level circuit schematic in Figure 3.3.
2026-09-15 Reframe Section 1.7 as a modular development methodology
    Replaces the iterative-prototyping framing with a modular one that
    matches the six functional modules already used to organize Chapter
    Three (Core Processing, Power Management, Locomotion, Sensor and
    Navigation, Actuators, Telemetry), each built and bench-tested
    largely on its own before integration. Also drops "planting depth
    consistency" from the listed evaluation metrics here, since depth
    control was scoped to future work earlier.
2026-09-15 Add methodology diagrams, mission flowchart, and math formulation
    Adds Figures 1.3 and 1.4 (generic modular methodology, then applied
    to this project's six modules) at the end of Section 1.7, and Figure
    3.13 (the runtime mission flowchart) at the end of Chapter Three.
    Adds a new Section 3.8.5 with the algorithms that are actually
    implemented as formulas in the firmware: the boustrophedon grid
    position, the barometric elevation tare, and battery voltage sensing
    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
2026-09-15 Fix battery voltage divider multiplier to match B25 module (5:1)
    The firmware scaled the analogue reading by 2.0, matching a 1:1
    divider. That's wrong for the installed B25 voltage sensor module,
    which is a fixed 5:1 divider (30k/7.5k) rated for 0-25V input mapped
    to 0-5V output. At 2x, a fully charged 12V battery would put over
    5V onto the analogue pin, above its rated input, and the reading
    would be half of the actual battery voltage besides. Corrected to
    5.0 to match the real hardware, and updated the two places in the
    docs that repeated the old 10k/10k, 2x description.
    Also updates the thesis's Section 3.8.5 to reflect the fix instead
    of flagging it as an open discrepancy.
    [MaizeRover_Phase2_Master.ino]
2026-09-15 Report real database status in the health endpoint
    /api/health hardcoded database: "connected" regardless of whether
    the PostgreSQL connection actually succeeded. Exposes the real
    isPostgresAvailable flag from db.js so the health check (and the
    frontend's Test Connection feature, which calls this endpoint)
    reflects whether telemetry is actually landing in Postgres or
    silently falling back to the server's in-memory store.
2026-09-15 feat(firmware): add straight line motor diagnostic test sketch (2s drive, stop, 5 cycles)
2026-09-15 fix(firmware): set fixed motor wiring (Left: 3,5, EN=4 | Right: 6,9, EN=8)
    [straight_line_motor_test.ino]
2026-09-15 fix(firmware): apply working motor drive functions, driver enable, and right-side inversion to master firmware
    [MaizeRover_Phase2_Master.ino]
2026-09-15 Add Mission Control page for the local-first connect/config/run flow
    Wires the new firmware mission lifecycle (config, start_mission,
    pause_mission, resume_mission, status) into the app with a single page:
    enter the rover's LAN IP, apply grid/PID parameters, start or pause a
    mission, and watch live progress. Telemetry is polled directly from the
    rover over the LAN and logged straight into this device's local IndexedDB
    as the mission runs, so a completed run shows up in Mission Hub/Analytics
    with no server or internet connection involved.
    Also fixes sendRoverCommand's direct-LAN path, which built the command URL
    from the action alone and silently dropped any params, so config values
    never re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
2026-09-15 fix(firmware): restore runtime-configurable mission parameters after merge
    The merge of the motor-wiring fixes from main turned BASE_SPEED, TURN_SPEED,
    DROP_SPACING_M, ROW_SPACING_M, DROPS_PER_ROW, and MOIST_THRESHOLD back into
    const, and dropped the TOTAL_ROWS declaration entirely, while the config
    command handler still assigns to all of them and the status/loop code still
    reads TOTAL_ROWS. That combination does not compile. Restoring these as
    plain mutable globals keeps the local mission-config flow (config,
    start_mission, pause_mission, resume_mission, status) working alongside the
    new motor driver fixes.
    [MaizeRover_Phase2_Master.ino]
2026-09-15 Switch R4 to Access Point mode, drop on-device cloud push
    Range is roughly the same either way, but hosting its own network gets the
    rover a fixed, known address (192.168.4.1) instead of whatever a phone
    hotspot's DHCP happens to hand out, and removes the dependency on that
    hotspot staying awake mid-mission. The app now defaults its rover IP to
    192.168.4.1, so a fresh install has nothing to configure: join the rover's
    network, open the app, connect.
    The trade-off is the rover no longer has its own path to the internet, so
    the on-device HTTPS push to the cloud API and its piggybacked E-Stop check
    are removed along with the WIFI_SSID/CLOUD_HOST config and the WiFiSSLClient
    plumbing. This does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
    [MaizeRover_Phase2_Master.ino]
2026-09-15 docs: bring architecture knowledge base in line with local-first + AP mode
    Rewrites the executive overview, edge-tier table, operational state machine,
    cloud backend section, and end-to-end sequence diagram to describe what the
    system actually does now: the rover hosts its own Access Point and never
    touches the internet, the companion app is the authoritative on-device
    mission log, and cloud sync is a manual, optional, post-mission step from
    the app via either the Vercel serverless functions or the self-hosted
    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
2026-09-15 Auto-start mission 3s after applying config, with a cancelable countdown
    Applying a configuration while the rover is IDLE now begins a 3-second
    countdown banner ("Starting mission in 3...") instead of requiring a
    separate Start Mission tap. A Cancel button aborts it, and the countdown
    re-checks the rover's latest known mode right before firing start_mission
    in case something changed during the window (e.g. an E-Stop). Manually
    starting or pausing the mission also cancels any pending countdown to
    avoid a double dispatch.
    Caught and fixed a real bug while testing this: the countdown's tick logic
    initially called startMission() from inside a setCountdown() updater
    function. React (in StrictMod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
2026-09-15 fix(firmware): correct Content-Length mismatch on /cmd HTTP responses
    client.println(resp) appended a trailing CRLF the browser wasn't told
    about (Content-Length declared resp.length(), but two more bytes actually
    followed), and client.stop() ran immediately after the write with nothing
    guaranteeing the SPI-linked WiFi coprocessor had actually pushed the body
    out first. Either could produce a response whose body doesn't parse as
    clean JSON on the client side. Switched to client.print (matches the
    declared length exactly) plus an explicit flush and a short delay before
    closing the socket.
    [MaizeRover_Phase2_Master.ino]
2026-09-15 fix: stop masking rover errors behind a dead cloud-relay fallback
    sendRoverCommand tried the rover's own Access Point first, but on ANY
    failure there (network error or bad JSON) it silently swallowed that error
    and fell back to relaying the command through the Dokploy/Vercel cloud API.
    That fallback made sense in the old cloud-first architecture, where the
    rover polled the cloud for queued commands during its telemetry push. It
    no longer does that at all -- that polling was removed when the firmware
    switched to Access Point mode and lost its own internet path. So the
    fallback could now only do one of two bad things: fail with a confusing,
    unrelated error (a Vercel error page isn't JSON eithe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
2026-09-16 fix: serialize all requests to the rover to stop overlapping connections
    Mission Control polls /cmd?action=status every 1.5s in the background for
    the whole time it's connected, with nothing stopping a user-triggered
    command (or the 3s auto-start countdown) from firing at the same moment a
    poll is in flight. The rover's WiFiServer on port 8080 is a tiny
    single-threaded, single-client-at-a-time Arduino HTTP server -- exactly
    the kind of thing that can garble a response if a second connection lands
    on it while the first is still being written.
    This matches what was reported: the config command (issued when nothing
    else was in flight) parsed fine, but the auto-fired start_mission call at
    the e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
2026-09-16 fix(firmware): guard BME280 reads so a missing sensor can't break telemetry JSON
    Root cause of the "invalid JSON" error, finally confirmed from the raw
    response: with the BME280 not connected, bme.readTemperature() (and
    readHumidity/readPressure/readAltitude) return NaN, and String(NaN, n)
    renders as the literal text "nan". That lands straight in the status JSON
    as "tempC":nan -- not a valid JSON number -- which breaks parsing of the
    entire response, not just that one field. Every other sensor path already
    had a safe fallback (ultrasonic timeout, GPS validity check, MPU/compass
    I2C failure); the BME280 reads were the one gap.
    Promotes the existing bmeReady flag (previously local to setup(),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
    [MaizeRover_Phase2_Master.ino]
2026-09-16 feat(firmware): actually drive between drops -- compass+gyro PID + U-turns
    The root cause of "mission starts but the rover doesn't move": AUTO mode
    called executePlantingDrop() every 2.5s, but that function only computed
    synX/synY math and fired the seed/pump actuators -- it never once called a
    drive function. This has been a known, explicitly-flagged gap since local-
    first mission control was first built; there's finally a real rover to
    close it on.
    Ports a bench-validated closed-loop driving approach (confirmed working
    against this exact hardware, previously tested with motor enable pins tied
    directly to 5V) into the master firmware's non-blocking, command-server-
    driven architecture:
    -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
    [MaizeRover_Phase2_Master.ino]
2026-09-16 Adopt dual-MPU-6050 steering, drop compass and BME280
    The magnetometer proved too noisy this close to the drive motors on the
    physical rover, so steering now holds a local relative-yaw reference
    (gyro-integrated P+I+D) from a dedicated MPU-6050 at 0x68, with a second
    MPU-6050 at 0x69 sensing terrain roughness via Z-axis shock. Ported this
    bench-validated approach into the full master firmware rather than
    replacing it outright, so the app-facing command set (config,
    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
2026-09-16 Remove ultrasonic obstacle sensor and arm servo (physically removed from rover)
    Confirmed with the user that the HC-SR04 ultrasonic sensor and the
    articulated soil-probe arm servo have been physically removed from the
    hardware. Deletes their firmware code (readUltrasonicCM, obstacle checks in
    the main loop and driveStraightPID, arm servo init/toggle), the obsDist
    status/CSV field, and the app's test_arm command/button and obsDist type,
    rather than zeroing them like the earlier BME280/compass removal -- a fake
    "0cm to obstacle" reading would be actively misleading, not just absent.
    Also carries over the remaining fixes from reviewing the user's latest bench
    firmware: globalYaw now resets to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
    [MaizeRover_Phase2_Master.ino]
